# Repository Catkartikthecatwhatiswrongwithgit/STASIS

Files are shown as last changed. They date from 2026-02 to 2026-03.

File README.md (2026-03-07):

<div align="center">

```
███████╗ ████████╗  █████╗  ███████╗ ██╗ ███████╗
██╔════╝ ╚══██╔══╝ ██╔══██╗ ██╔════╝ ██║ ██╔════╝
███████╗    ██║    ███████║ ███████╗ ██║ ███████╗
╚════██║    ██║    ██╔══██║ ╚════██║ ██║ ╚════██║
███████║    ██║    ██║  ██║ ███████║ ██║ ███████║
╚══════╝    ╚═╝    ╚═╝  ╚═╝ ╚══════╝ ╚═╝ ╚══════╝
```

**Autonomous Hazard Monitoring Rover**
*Team EDGECASE*




[]()

</div>

---

## What is STASIS?

STASIS is a compact autonomous rover built for reliable real-world operation on a student budget. It patrols a defined area, detects hazards (fire, motion, seismic activity), sends SMS alerts, and returns to a charging dock using AprilTag visual guidance — all without human intervention.

It is designed to **work at a demo**, not just in a lab.

---

## System Architecture

```
┌───────────────────────────────────────────────────────────────┐
│                      ROVER  (Mobile)                          │
│                                                               │
│   ┌─────────────┐  UART   ┌────────────────────────────────┐  │
│   │  ESP32-CAM  │────────►│          ESP32-S3              │  │
│   │  (Vision)   │         │  State machine · Motors        │  │
│   └─────────────┘         │  Sensors · GPS · GSM · UART    │  │
│                           └──────────────┬─────────────────┘  │
│                                          │ ESP-NOW             │
└──────────────────────────────────────────┼─────────────────────┘
                                           │
┌──────────────────────────────────────────┼─────────────────────┐
│                   BASE STATION           │  (Static)           │
│                                          ▼                     │
│   ┌──────────────────┐  UART  ┌──────────────────┐            │
│   │   Raspberry Pi   │◄──────►│    ESP32-C3       │            │
│   │   Zero W         │        │  (Wireless bridge)│            │
│   │   Flask + SocketIO        └──────────────────┘            │
│   └────────┬─────────┘                                         │
│            │ HTTP + Socket.IO                                  │
└────────────┼──────────────────────────────────────────────────┘
             ▼
    ┌──────────────────────────┐
    │     Web Dashboard        │
    │  stasis_app/index.html   │   offline-safe, served from Pi
    └──────────────────────────┘
```

---

## Hardware

### Rover

| Component | Part | Role |
|---|---|---|
| Main MCU | ESP32-S3 | State machine, motor control, sensor fusion |
| Vision | ESP32-CAM (AI Thinker) | Fire / motion / human detection |
| Motor Driver | L9110S | 4WD differential drive |
| Obstacle | HC-SR04 | Non-blocking ultrasonic — stops at 25 cm |
| Temperature | DS18B20 | Environmental monitoring, fire threshold |
| Light | LDR | Ambient light / smoke indicator |
| GPS | NEO-6M | Geofence enforcement + home position |
| GSM | SIM800L | SMS alerts on hazard or geofence breach |
| Battery | 2S Li-ion 7.4 V | Monitored via ADC + 30k/10k divider |

### Base Station

| Component | Part | Role |
|---|---|---|
| Supervisor | Raspberry Pi Zero W | Flask API, AprilTag docking, PDF reports |
| Bridge | ESP32-C3 | ESP-NOW ↔ UART relay |
| Tag | tag36h11 ID 0, 10 cm | Visual beacon on docking station |

---

## State Machine

```
             ┌──────────────┐
   ┌─────────│  SAFE_IDLE   │◄──────────────────────┐
   │         └──────┬───────┘                       │
   │                │ PATROL or cmd                 │
   │                ▼                               │
   │         ┌──────────────┐  geofence/hazard      │
   │         │   PATROL     │────────────┐          │
   │         └──────┬───────┘            │          │
   │                │ hazard             │          │
   │                ▼                   │          │
   │         ┌──────────────┐           │          │
   │         │    ALERT     │─────timeout 30s──────►│
   │         └──────────────┘                      │
   │                                               │
   │  low bat / geofence                           │
   │         ┌──────────────┐                      │
   └────────►│ RETURN_BASE  │                      │
             └──────┬───────┘                      │
                    │ dockingEnabled                │
                    ▼                              │
             ┌──────────────┐  voltage rise        │
             │   DOCKING    │─────────────────────►│
             │ (AprilTag)   │                      │
             └──────────────┘                      │
                    │ docked                       │
                    ▼                              │
             ┌────────────────────┐                │
             │  DOCKED_CHARGING   │                │
             │  motors disabled   │────undocked───►│
             └────────────────────┘
```

| State | Description |
|---|---|
| `SAFE_IDLE` | Motors off, sensors active, waiting for command |
| `PATROL` | Autonomous patrol within GPS geofence |
| `ALERT` | Hazard confirmed — buzzer on, SMS sent, investigating |
| `RETURN_TO_BASE` | Low battery or geofence breach — heading home |
| `DOCKING` | Pi-guided AprilTag precision approach |
| `DOCKED_CHARGING` | Passive contact charging — motors fully disabled |

---

## AprilTag Docking

The Pi Zero runs a continuous visual docking control loop whenever the rover enters `STATE_DOCKING`.

```
ESP32-CAM MJPEG stream
        │
        ▼
  Pi Zero  (pupil-apriltags + OpenCV)
        │  detect tag36h11 ID 0
        │  measure: X error (steering) + Z depth (distance)
        ▼
  Proportional controller
    turn  = clamp(err_x × 0.6,  -100, +100)
    speed = clamp(dist_m × 40,    10,    40)
    if |err_x| < 15 px → turn = 0  (dead-band)
    if dist_m  < 0.25 m → DOCKED
        │
        ▼
  6-byte binary packet   [0xAA | turn | speed | docked | XOR | 0x55]
        │
        ▼
  UART → ESP32-C3 → ESP-NOW → ESP32-S3 → motors
```

**One-time setup on Pi:**
```bash
pip install pupil-apriltags opencv-python-headless
```

Print a `tag36h11` tag at **10 cm**, ID **0**. Mount it vertically on the docking station, facing the rover's approach path. Ensure there is consistent lighting.

---

## Quick Start

### 1. Flash firmware

```bash
# ESP32-S3 (rover main controller)
# Open: rover_main/rover_main.ino
# Board: ESP32S3 Dev Module  |  Upload speed: 921600

# ESP32-CAM (vision)
# Open: cam_firmware/cam_firmware.ino
# Board: AI Thinker ESP32-CAM  |  Connect IO0→GND during flash only

# ESP32-C3 (wireless bridge)
# Open: base_bridge/base_bridge.ino
# Board: ESP32C3 Dev Module
# ⚠  Set roverMac[] to your ESP32-S3's actual MAC address before flashing
```

### 2. Set up the Pi

```bash
# Install Python dependencies
pip install flask flask-cors flask-socketio pyserial fpdf2 eventlet
pip install pupil-apriltags opencv-python-headless

# Cache Leaflet maps for offline use (run once with internet access)
mkdir -p ~/stasis/static
wget -O ~/stasis/static/leaflet.css https://unpkg.com/leaflet@1.9.4/dist/leaflet.css
wget -O ~/stasis/static/leaflet.js  https://unpkg.com/leaflet@1.9.4/dist/leaflet.js

# Start the base station
python3 base_station/station_monitor.py
```

### 3. Auto-start on boot

```bash
sudo nano /etc/systemd/system/stasis.service
```

```ini
[Unit]
Description=STASIS Base Station
After=network.target

[Service]
User=pi
WorkingDirectory=/home/pi/stasis
ExecStart=/usr/bin/python3 /home/pi/stasis/base_station/station_monitor.py
Restart=always
RestartSec=10
Environment="SERIAL_PORT=/dev/serial0"
Environment="CAM_STREAM_URL=http://192.168.4.1:81/stream"

[Install]
WantedBy=multi-user.target
```

```bash
sudo systemctl daemon-reload && sudo systemctl enable --now stasis
```

### 4. Open the dashboard

Connect to the `Stasis-Base` WiFi AP (password: `stasis123`), then visit:

```
http://192.168.4.1:5000/stasis_app/index.html
```

---

## Commands

| Command | Action |
|---|---|
| `STOP` | Emergency stop → SAFE_IDLE |
| `FORWARD` | Drive forward |
| `BACKWARD` | Drive in reverse |
| `LEFT` / `RIGHT` | Turn |
| `PATROL` | Start autonomous patrol |
| `STOP_PATROL` | Stop patrol → SAFE_IDLE |
| `HOME` / `RETURN_BASE` | Return to dock |
| `DOCKING` | Enable AprilTag docking |
| `DISABLE_DOCKING` | Cancel docking |
| `SETHOME` | Save current GPS position as home |
| `RESET` | Reset all flags and states |

---

## Safety Features

| Feature | How it works |
|---|---|
| Obstacle stop | HC-SR04 non-blocking; halts at < 25 cm |
| GPS geofence | 50 m radius, Haversine calculation, 80 % hysteresis on re-entry |
| GPS staleness guard | `SAFE_HALT` if no fix > 5 s; 90 s grace period after cold boot |
| Dock detection | 0.4 V battery rise sustained across 20 frames (~2 s) |
| Emergency stop | `ledcWrite(pin, 0)` on all PWM channels — LEDC-safe |
| GSM brownout guard | Motors halted 100 ms before every SMS attempt |
| SMS rate limit | Maximum one SMS per 60 seconds |
| Low battery | Speed capped at 60 % below 20 %; `RETURN_TO_BASE` triggered |
| Hard voltage cutoff | Forced `SAFE_IDLE` at 6.2 V |
| Charge complete | Detected at 8.4 V or after 10-minute timeout |

---

## Repository Structure

```
STASIS/
├── rover_main/
│   └── rover_main.ino           ESP32-S3 main firmware
├── cam_firmware/
│   └── cam_firmware.ino         ESP32-CAM vision firmware
├── base_bridge/
│   └── base_bridge.ino          ESP32-C3 wireless bridge
├── base_station/
│   └── station_monitor.py       Pi: Flask API + AprilTag docking thread
├── stasis_app/
│   └── index.html               Web dashboard (offline-safe single file)
├── docking/
│   └── apriltag_docking.py      Standalone AprilTag docking utility
└── docs/
    ├── ESP32-S3_INSTRUCTIONS.md
    ├── ESP32-CAM_INSTRUCTIONS.md
    ├── ESP32-C3_INSTRUCTIONS.md
    ├── RPI0_INSTRUCTIONS.md
    ├── APRILTAG_DOCKING_GUIDE.md
    ├── WIRING_DIAGRAMS.md
    ├── PROTOCOL.md
    ├── QUICK_REFERENCE.md
    ├── SSH_PI0_SETUP.md
    └── 3D_PRINTED_PARTS.md
```

---

## Pin Reference (ESP32-S3)

| GPIO | Function | Notes |
|---|---|---|
| 1 | Battery ADC | 30 kΩ / 10 kΩ divider → reads 0–3.3 V for 0–13.2 V |
| 2 | Motor A DIR | L9110S |
| 4 | Motor A PWM | L9110S — LEDC channel |
| 5 | Motor B PWM | L9110S — LEDC channel |
| 6 | Motor C PWM | L9110S — LEDC channel |
| 7 | Motor C DIR | L9110S |
| 8 | GPS Serial2 RX | NEO-6M TX |
| 9 | Ultrasonic ECHO | HC-SR04 |
| 10 | Ultrasonic TRIG | HC-SR04 |
| 12 | SIM800 RX | **Serial1** — not Serial2 |
| 13 | SIM800 TX | **Serial1** — not Serial2 |
| 14 | Buzzer | Active buzzer |
| 15 | Motor D PWM | L9110S — LEDC channel |
| 16 | Motor D DIR | L9110S |
| 18 | Motor B DIR | L9110S |
| 19 | GPS Serial2 TX | NEO-6M RX |
| 21 | DS18B20 | OneWire + 4.7 kΩ pull-up to 3.3 V |
| 43 | UART1 TX | Pi Zero RX (via ESP32-C3) |
| 44 | UART1 RX | Pi Zero TX (via ESP32-C3) |
| 45 | Status LED | – |

---

## Changelog — v2 (March 2026)

| # | Issue | Fix |
|---|---|-----|
| C1 | `estop()` used `digitalWrite` on LEDC pins — motors did not stop | Changed to `ledcWrite(pin, 0)` |
| C2 | `BACKWARD` command called `drive(0,0)` immediately, cancelling the speed | Fixed to set `currentSpeed = -50` |
| C3 | `chargeBeepDone` declared as local `static` inside `executeState()`, shadowing global | Removed local declaration; uses global |
| C4 | GPS and SIM800 both on Serial2 — corrupted each other | SIM800 moved to Serial1 (pins 12, 13) |
| C5 | Global variables used but never declared — code would not compile | Added full globals block after enum declarations |
| C6 | AprilTag docking existed in spec but was not implemented anywhere | Full Pi-side docking thread added to `station_monitor.py` |
| C7 | `uartTask` only called `parseDockCommand` on the header byte; bytes 2–6 routed to text parser | Added `binaryMode` flag to capture entire packet |
| I1 | `captureAndSend()` wrote raw binary struct then text on same Serial — corrupted S3 parser | Binary write removed; text-only output |
| I2 | GPS staleness check halted rover immediately on cold boot before any fix acquired | Added 90-second startup grace period |
| I3 | FreeRTOS task stacks set to 2048 bytes — overflowed on String / float operations | Increased to 3072–4096 bytes per task |
| W1 | `L is not defined` (×6) — Leaflet CDN unavailable on isolated AP network | Dynamic loader: CDN → `/static/leaflet.js` → offline message |
| W2 | Chat used raw `WebSocket` — Flask-SocketIO uses Socket.IO framing, not raw WS | Replaced with Socket.IO `io()` client |
| W3 | Font Awesome CDN missing on offline AP — all icons blank | Replaced with inline SVG, zero CDN dependency |

---

*Team EDGECASE · March 2026*

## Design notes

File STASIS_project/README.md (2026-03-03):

# STASIS Autonomous Rover — Team EDGECASE

STASIS is a compact autonomous hazard-monitoring rover designed for reliable real-world operation under tight budget constraints.

This project focuses on robustness, deterministic behavior, and competition-ready autonomy rather than experimental features.

---

## Core Capabilities

* Autonomous patrol
* Obstacle avoidance (HC-SR04)
* Environmental sensing (DS18B20, LDR)
* GPS tracking with virtual geofence (NEO-6M)
* GSM hazard alerts (SIM800)
* AprilTag-assisted precision docking
* Passive contact-pad charging
* Multi-MCU distributed architecture
* Raspberry Pi mission logging
* Live telemetry dashboard

---

## System Architecture

### Rover (ESP32-S3)

Primary responsibilities:

* state machine control
* motor control (L9110S)
* sensor fusion
* dock detection
* return-to-base logic
* GSM alert triggering

### Vision Node (ESP32-CAM)

* AprilTag detection
* snapshot capture
* hazard flag signaling

### Base Bridge (ESP32-C3)

* wireless/serial relay
* packet forwarding
* base communications

### Supervisor (Raspberry Pi Zero W)

* mission logging
* evidence storage
* dashboard hosting
* system monitoring

---

## Charging System

STASIS uses passive contact-pad charging:

Dock side:

* regulated 5V supply
* exposed screw-head contacts
* mechanical alignment funnel

Rover side:

* spring metal wipers
* onboard Li-ion charger

Dock detection is performed via battery voltage rise with hysteresis filtering.

---

## Rover State Machine

Primary states:

* PATROL
* ALERT
* RETURN_TO_BASE
* DOCKED_CHARGING
* SAFE_IDLE

All transitions are non-blocking and millis()-driven.

---

## Repository Structure

* rover_s3_firmware/ — main rover firmware
* cam_firmware/ — ESP32-CAM code
* base_bridge/ — ESP32-C3 bridge
* base_station/ — Raspberry Pi services
* stasis_app/ — web dashboard
* docking/ — AprilTag utilities
* docs/ — system documentation

---

## Design Philosophy

STASIS prioritizes:

* deterministic behavior
* electrical tolerance
* mechanical forgiveness
* low-cost components
* competition reliability

This is a field-robust student platform, not a lab-only prototype.

---

## Status

Active development.
Focused on competition reliability and system hardening.

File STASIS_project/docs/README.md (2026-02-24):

# STASIS - Autonomous Environmental Monitoring Rover

A production-ready autonomous rover system for environmental monitoring, hazard detection, and autonomous docking. Built with ESP32-S3, Raspberry Pi Zero, and modular sensor integration.

---

## System Architecture

```
┌─────────────────────────────────────────────────────────────────────────────┐
│                           STASIS ROVER SYSTEM                                │
├─────────────────────────────────────────────────────────────────────────────┤
│                                                                             │
│   ┌──────────────┐    ┌──────────────┐    ┌──────────────┐                 │
│   │   ROVER     │    │    BASE      │    │   REMOTE    │                 │
│   │   (Mobile)  │◄──►│  (Station)   │◄──►│  (Dashboard)│                 │
│   └──────┬───────┘    └──────┬───────┘    └──────────────┘                 │
│          │                   │                                             │
│          │    ┌──────────────┴───────┐                                   │
│          │    │   COMMUNICATION      │                                   │
│          │    │   • ESP-NOW          │                                   │
│          │    │   • UART (Pi↔ESP32)  │                                   │
│          │    │   • WiFi (Dashboard) │                                   │
│          │    └───────────────────────┘                                   │
│          │                                                                   │
│   ┌──────┴────────────────────────────────────────────────────────┐       │
│   │                     ROVER HARDWARE                             │       │
│   ├───────────────────────────────────────────────────────────────┤       │
│   │  ESP32-S3 (Main Controller)                                   │       │
│   │    ├── Navigation & State Machine                            │       │
│   │    ├── Motor Control (L9110S)                                │       │
│   │    ├── Sensor Fusion                                         │       │
│   │    └── Communication Bridge                                  │       │
│   │                                                               │       │
│   │  ESP32-CAM (Vision)                                          │       │
│   │    ├── Fire Detection                                         │       │
│   │    ├── Human Detection                                        │       │
│   │    └── Tree Detection                                         │       │
│   │                                                               │       │
│   │  Sensors                                                     │       │
│   │    ├── DS18B20 (Temperature)                                 │       │
│   │    ├── HC-SR04 (Ultrasonic)                                  │       │
│   │    ├── MPU6050 (Tilt/Seismic)                               │       │
│   │    └── Neo-6M (GPS)                                          │       │
│   │                                                               │       │
│   │  Communication                                                │       │
│   │    ├── SIM800 (SMS Alerts)                                   │       │
│   │    └── ESP-NOW (Base Link)                                   │       │
│   └───────────────────────────────────────────────────────────────┘       │
│                                                                             │
└─────────────────────────────────────────────────────────────────────────────┘
```

---

## Hardware List

### Rover
| Component | Model | Purpose |
|---|---|---|
| Main MCU | ESP32-S3 | Navigation, state machine, motor control |
| Camera | ESP32-CAM | Fire/human/tree detection |
| Motor Driver | L9110S | 4WD differential drive |
| Temperature | DS18B20 | Environmental monitoring |
| Ultrasonic | HC-SR04 | Obstacle avoidance |
| IMU | MPU6050 | Tilt/seismic detection |
| GPS | Neo-6M | Location tracking |
| Modem | SIM800 | SMS alerts |
| Battery | LiPo 3S | Power |

### Base Station
| Component | Model | Purpose |
|---|---|---|
| Processing | Raspberry Pi Zero | AprilTag detection |
| Bridge | ESP32-C3 | UART↔ESP-NOW |
| Vision | USB Camera | AprilTag detection |
| Display | I2C LCD | Status display |
| Tag | AprilTag 36h11 | Docking beacon |

---

## State Machine

```
                    ┌──────────────────────────────────────┐
                    │                                      │
                    ▼                                      │
    ┌───────────────────────────┐                          │
    │         PATROL            │◄─────────────────────────┤
    │  (Normal operation)       │                          │
    └─────────────┬─────────────┘                          │
                  │                                         │
    ┌─────────────┴─────────────┐     ┌───────────────────┐ │
    │                           │     │                   │ │
    ▼                           ▼     ▼                   ▼ │
┌────────────┐  ┌──────────────────┐  ┌────────────────┐    │
│  RESEARCH  │  │ RETURN_TO_BASE  │  │     DOCKING    │    │
│(Data collect)│ │ (Low battery)   │  │ (AprilTag)    │    │
└──────┬──────┘  └────────┬─────────┘  └───────┬────────┘    │
       │                 │                      │             │
       │    ┌────────────┴──────────┐           │             │
       │    │                      │           │             │
       ▼    ▼                      ▼           ▼             │
┌──────────────────────────────────────────────────────────┐ │
│                        ALERT                              │ │
│  (Fire/Earthquake/Intruder - Investigate & Alert)       │ │
└──────────────────────────────────────────────────────────┘ │
                              │                              │
                              │     ┌───────────────────────┘
                              │     │
                              ▼     ▼
                    ┌──────────────────┐
                    │     DOCKED       │
                    │ (Charging/Idle)  │
                    └──────────────────┘
```

### State Transitions

| From State | To State | Trigger Condition |
|---|---|---|
| PATROL | RESEARCH | Timer or command |
| PATROL | ALERT | fireDetected OR humanDetected OR tiltDetected |
| PATROL | RETURN_TO_BASE | batteryPercent < 30% |
| PATROL | DOCKING | dockingEnabled = true |
| RESEARCH | PATROL | Timeout (5 min) |
| RESEARCH | ALERT | Hazard detected |
| ALERT | PATROL | Timeout or resolved |
| RETURN_TO_BASE | DOCKING | dockingEnabled = true |
| DOCKING | DOCKED | Successfully docked |
| DOCKED | PATROL | dockingEnabled = false |

---

## Folder Structure

```
STASIS-Rover/
├── .gitignore
├── README.md
├── LICENSE
│
├── rover_s3_firmware/          # ESP32-S3 main controller
│   ├── platformio.ini
│   ├── src/
│   │   └── rover_main.cpp
│   └── lib/
│       └── (dependencies)
│
├── esp32_cam_firmware/         # ESP32-CAM vision
│   ├── cam_firmware.ino
│   └── libraries/
│
├── base_station_c3/            # ESP32-C3 bridge
│   ├── platformio.ini
│   └── src/
│       └── bridge.cpp
│
├── pi_zero_station/            # Raspberry Pi Zero
│   ├── requirements.txt
│   ├── apriltag_docking.py    # AprilTag detection + control
│   ├── station_monitor.py     # Main station logic
│   └── config/
│       └── camera_calibration.json
│
├── cad/                        # 3D printed parts
│   └── (STL files)
│
└── docs/
    ├── PROTOCOL.md            # Communication protocols
    ├── HARDWARE.md           # Wiring diagrams
    ├── CALIBRATION.md        # Sensor calibration
    └── TROUBLESHOOTING.md    # Common issues
```

---

## Quick Start

### 1. Hardware Assembly

1. **Motor Driver**: Connect L9110S to ESP32-S3 GPIO pins (see `WIRING_DIAGRAMS.md`)
2. **Sensors**: Wire DS18B20, HC-SR04, MPU6050 per pin definitions
3. **GPS**: Connect Neo-6M to UART2
4. **SIM800**: Connect to UART0 with level shifting

### 2. Base Station Setup

```bash
# Install dependencies
cd pi_zero_station
pip install -r requirements.txt

# Run AprilTag docking system
python apriltag_docking.py --device /dev/ttyUSB0
```

### 3. Rover Flash

```bash
# Using PlatformIO
cd rover_s3_firmware
pio run --target upload
```

### 4. Commissioning

1. Verify all sensors respond
2. Test motor direction
3. Calibrate camera focal length
4. Test AprilTag detection at various distances
5. Verify ESP-NOW pairing

---

## Command Protocol

### Pi Zero → ESP32-S3 (Docking)

| Byte | Field | Range |
|---|---|---|
| 0 | HEADER | 0xAA |
| 1 | turn | -100 to +100 |
| 2 | speed | 0-100 |
| 3 | docked | 0 or 1 |
| 4 | checksum | XOR(1,2,3) |
| 5 | TAIL | 0x55 |

### ESP32-S3 → Base (Telemetry)

See `docs/PROTOCOL.md` for full specification.

---

## Current Limitations

- **GPS**: Neo-6M requires clear sky view; indoor operation limited
- **AprilTag**: Requires adequate lighting; performance degrades in low-light
- **WiFi**: Range limited to ~100m outdoors; use ESP-NOW for extended range
- **Battery**: Actual runtime depends on terrain and load; 30% threshold is conservative

---

## Future Work

- [ ] Implement SLAM for autonomous navigation
- [ ] Add machine learning for hazard classification
- [ ] Multi-rover coordination via ESP-NOW mesh
- [ ] Solar charging integration
- [ ] Web interface for real-time monitoring

---

## License

MIT License - See LICENSE file

---

## Authors

- EdgeCase Team

## Acknowledgments

- AprilTag library by University of Michigan
- ESP32 Arduino framework

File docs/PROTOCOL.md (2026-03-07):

# STASIS Communication Protocols

---

## Architecture Summary

```
ESP32-CAM ──Serial──► ESP32-S3 ──ESP-NOW──► ESP32-C3 ──UART──► Raspberry Pi
                        (rover)              (bridge)             (Flask API)
                           ▲                                          │
                           └──────────── binary DockCommand ◄─────────┘
                                         (during docking only)
```

---

## 1. Camera → Rover (Serial, UART0)

The ESP32-CAM sends plain-text messages to the ESP32-S3 over its default Serial port at 115200 baud.

**Output from ESP32-CAM:**

| Message | Meaning |
|---|---|
| `CAM:READY` | Camera initialised successfully |
| `CAM:ERROR` | Camera failed to initialise |
| `HAZARD:FIRE` | Fire pixels detected above threshold |
| `HAZARD:MOTION` | Motion pixels detected above threshold |
| `HAZARD:HUMAN` | Skin-tone pattern detected above threshold |
| `CLEAR` | No hazards in current frame |

> **Note (v2):** Binary `DetectionResult` struct writes were removed. All output is text-only. This eliminates corruption of the S3's line parser.

**Commands from ESP32-S3 to ESP32-CAM (single byte):**

| Byte | Command | Effect |
|---|---|---|
| `0x01` | CAPTURE | Capture one frame and return detection result |
| `0x02` | STREAM_ON | Start continuous MJPEG stream |
| `0x03` | STREAM_OFF | Stop streaming |
| `0x04` | DETECT | Run detection only, no stream |
| `0x05` | APRIL_STREAM | Switch to JPEG mode and start streaming (for AprilTag) |

---

## 2. Rover → Base (ESP-NOW, wireless)

The ESP32-S3 broadcasts telemetry to the ESP32-C3 bridge via ESP-NOW at approximately 1 Hz.

**Telemetry packet (JSON, forwarded to Pi over UART):**

```json
{
  "id":       123,
  "temp":     25.5,
  "bat":      82.0,
  "lat":      12.345678,
  "lng":      77.123456,
  "hazard":   false,
  "status":   "PATROL",
  "distance": 142.3,
  "speed":    40,
  "heading":  180.0
}
```

| Field | Type | Description |
|---|---|---|
| `id` | int | Incrementing packet counter |
| `temp` | float | DS18B20 temperature in °C |
| `bat` | float | Battery percentage (0–100) |
| `lat` / `lng` | float | GPS coordinates (decimal degrees) |
| `hazard` | bool | True if any hazard is active |
| `status` | string | Current state name |
| `distance` | float | Ultrasonic reading in cm |
| `speed` | int | Current motor speed (0–100) |
| `heading` | float | Compass heading in degrees (if available) |

**Status values:**

| Value | State |
|---|---|
| `SAFE_IDLE` | Idle |
| `PATROL` | Autonomous patrol |
| `ALERT` | Hazard detected |
| `RETURN_TO_BASE` | Returning home |
| `DOCKING` | AprilTag approach active |
| `DOCKED_CHARGING` | On charge |

---

## 3. Pi → Rover (UART → ESP32-C3 → ESP-NOW)

### 3a. Text commands (all states except DOCKING)

Plain text strings terminated with `\n`. The bridge forwards them to the rover via ESP-NOW.

| Command | Effect |
|---|---|
| `STOP` | Emergency stop |
| `FORWARD` | Drive forward at speed 50 |
| `BACKWARD` | Drive in reverse at speed 50 |
| `LEFT` | Turn left |
| `RIGHT` | Turn right |
| `PATROL` | Start autonomous patrol |
| `STOP_PATROL` | Stop patrol |
| `HOME` / `RETURN_BASE` / `RETURN_HOME` | Return to dock |
| `DOCKING` / `ENABLE_DOCKING` | Activate docking mode |
| `DISABLE_DOCKING` | Cancel docking |
| `SETHOME` | Set current GPS as home |
| `ALERT` | Force ALERT state |
| `RESET` | Reset all state flags |

### 3b. Binary DockCommand packets (DOCKING state only)

During `STATE_DOCKING`, the Pi sends 6-byte binary packets at ~20 Hz. These bypass the text parser.

```
Byte  Field     Type    Range
  0   Header    uint8   0xAA  (fixed)
  1   turn      int8    -100 to +100  (negative = left, positive = right)
  2   speed     uint8   0 to 100
  3   docked    uint8   0 or 1
  4   checksum  uint8   XOR(byte1, byte2, byte3)
  5   Tail      uint8   0x55  (fixed)
```

The rover uses a `binaryMode` flag in `uartTask` to capture all 6 bytes before parsing. The `parseDockCommand()` function validates header, tail, and XOR checksum before accepting a packet.

---

## 4. Pi REST API

Base URL: `http://192.168.4.1:5000`

Most endpoints require the API key header: `X-API-Key: stasis-2024`

| Endpoint | Method | Auth | Description |
|---|---|---|---|
| `/api/health` | GET | No | Liveness check |
| `/api/status` | GET | Yes | Latest telemetry JSON |
| `/api/history` | GET | Yes | Telemetry history (`?limit=N`) |
| `/api/alerts` | GET | Yes | Alert history |
| `/api/stats` | GET | Yes | Daily statistics |
| `/api/command` | POST | Yes | Send command: `{"cmd": "PATROL"}` |
| `/api/reports` | GET | Yes | List PDF reports |
| `/api/reports/<file>` | GET | Yes | Download a report |
| `/api/export/csv` | GET | Yes | Export telemetry as CSV |
| `/api/export/json` | GET | Yes | Export telemetry as JSON |
| `/api/config` | GET/POST | Yes | Read / write config |

### Socket.IO events (real-time)

Connect with `io()` (no URL argument — auto-connects to origin).

| Event | Direction | Payload |
|---|---|---|
| `telemetry` | Server → Client | Latest telemetry object |
| `alert` | Server → Client | Alert object |
| `chat` | Bidirectional | `{user, message, channel, timestamp}` |
| `user_joined` | Server → Client | `{user}` |
| `user_left` | Server → Client | `{user}` |
| `apriltag` | Server → Client | `{found, tag_id, err_x, dist_m}` |
| `connected` | Server → Client | `{message}` on first connect |

---

## 5. Timing

| Data stream | Rate | Method |
|---|---|---|
| Rover telemetry | ~1 Hz | ESP-NOW broadcast |
| Dock command packets | ~20 Hz | UART binary during DOCKING only |
| Camera hazard messages | Event-driven | UART text |
| AprilTag Socket.IO events | ~20 Hz | Socket.IO during DOCKING only |
| Battery updates | 10 Hz | Internal (sensorTask) |
| GPS NMEA | 1 Hz | Serial2 hardware UART |

---

*Last updated: March 2026 — v2*

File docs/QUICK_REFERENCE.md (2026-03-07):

# STASIS — Quick Reference Card

---

## Commands

| Command | Action |
|---|---|
| `STOP` | Emergency stop → SAFE_IDLE |
| `FORWARD` | Drive forward |
| `BACKWARD` | Drive in reverse |
| `LEFT` / `RIGHT` | Turn |
| `PATROL` | Start autonomous patrol |
| `STOP_PATROL` | Stop patrol → SAFE_IDLE |
| `HOME` / `RETURN_BASE` | Return to dock |
| `DOCKING` | Enable AprilTag docking |
| `DISABLE_DOCKING` | Cancel docking |
| `SETHOME` | Set current GPS as home (requires fix) |
| `RESET` | Reset all flags and state |

---

## States

| State | LED | Buzzer |
|---|-----|---|
| `SAFE_IDLE` | 1 Hz slow blink | Off |
| `PATROL` | Solid | Off |
| `ALERT` | 5 Hz fast blink | 2 Hz |
| `RETURN_TO_BASE` | 2 Hz medium blink | Off |
| `DOCKING` | Off | Off |
| `DOCKED_CHARGING` | Solid | Off |

---

## Pin Map (ESP32-S3)

```
Motors:      2, 4, 5, 6, 7, 15, 16, 18   (L9110S 4WD)
Ultrasonic:  9 (ECHO), 10 (TRIG)          (HC-SR04)
GPS:         8 (RX), 19 (TX)              (NEO-6M, Serial2)
SIM800:      12 (RX), 13 (TX)             (Serial1 — NOT Serial2)
DS18B20:     21                            (OneWire + 4.7k pull-up)
Battery ADC: 1                             (30k/10k divider)
Buzzer:      14
Status LED:  45
UART to Pi:  43 (TX), 44 (RX)
```

> Serial2 = GPS only. Serial1 = SIM800 only. They must not be swapped.

---

## Safety Thresholds

| Parameter | Value |
|---|---|
| Obstacle stop | < 25 cm |
| Geofence radius | 50 m |
| GPS staleness halt | > 5 s (after 90 s cold-start grace) |
| Dock confirm voltage | +0.4 V above baseline |
| Dock debounce | 20 frames (~2 s) |
| Low battery speed limit | 20 % → 60 % speed cap |
| Hard voltage cutoff | 6.2 V |
| Charge complete | 8.4 V or 10 min |
| SMS cooldown | 60 s |

---

## AprilTag Docking Checklist

- [ ] Tag family: tag36h11, ID 0, size 10 cm
- [ ] Tag mounted perpendicular to approach path
- [ ] Consistent lighting on tag face
- [ ] `pip install pupil-apriltags opencv-python-headless` on Pi
- [ ] `CAM_STREAM_URL` set correctly (default: `http://192.168.4.1:81/stream`)
- [ ] Camera stream reachable: `curl -I http://192.168.4.1:81/stream`
- [ ] Rover reports `STATE_DOCKING` in telemetry to activate thread

---

## Dashboard Access

Connect to WiFi AP: **Stasis-Base** (password: `stasis123`)

```
Dashboard:  http://192.168.4.1:5000/stasis_app/index.html
API status: http://192.168.4.1:5000/api/health
API key:    stasis-2024
```

Keyboard shortcuts in dashboard:

| Key | Action |
|-----|---|
| `1`–`6` | Switch panel |
| `Space` | STOP |
| `P` | PATROL |
| `H` | HOME |
| `F` | Fencing panel |

---

## Common Problems

| Symptom | Fix |
|---|-----|
| Rover won't stop in emergency | Flash v2 firmware — `estop()` was broken |
| BACKWARD drives forward | Flash v2 firmware — speed sign was wrong |
| GPS halts rover on boot | Flash v2 firmware — 90 s grace period added |
| SMS sends but GPS garbled | SIM800 must be on Serial1, GPS on Serial2 |
| Docking doesn't steer | Check `binaryMode` flag in `uartTask` |
| `L is not defined` on dashboard | Cache Leaflet locally on Pi |
| Chat not working | Socket.IO required — not raw WebSocket |
| All dashboard icons blank | Inline SVG fix in v2 dashboard |
| Map shows in wrong place | Check GPS home fix, verify lat/lng sign |

---

## Useful Pi Commands

```bash
# Check service status
sudo systemctl status stasis

# View live logs
journalctl -u stasis -f

# Restart service
sudo systemctl restart stasis

# Test serial comms
minicom -D /dev/serial0 -b 115200

# Send a manual command
curl -X POST http://localhost:5000/api/command \
  -H "Content-Type: application/json" \
  -H "X-API-Key: stasis-2024" \
  -d '{"cmd":"STOP"}'
```

---

*Last updated: March 2026 — v2*

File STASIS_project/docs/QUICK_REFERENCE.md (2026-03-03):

================================================================================
STASIS ROVER - QUICK REFERENCE
================================================================================

## Commands
------------------------------------------------------------------------------
STOP              → Emergency stop
PATROL            → Start autonomous patrol
STOP_PATROL       → Stop patrol
HOME/RETURN_BASE  → Return to dock
DOCKING           → Enable AprilTag docking
SETHOME           → Set current GPS as home position
RESET             → Reset all states

## States
------------------------------------------------------------------------------
SAFE_IDLE         - Waiting, minimal power
PATROL            - Autonomous patrol
ALERT             - Hazard detected
RETURN_TO_BASE    - Returning home
DOCKING           - AprilTag approach
DOCKED_CHARGING   - Charging

## Safety Features
------------------------------------------------------------------------------
✓ Dock detection: 0.4V rise, 2s confirm, 20-frame debounce
✓ GPS geofence: 50m radius, ignores 0.0,0.0
✓ GPS staleness: SAFE_HALT after 5s no fix
✓ SIM800: Motors stop before SMS, 60s cooldown
✓ Ultrasonic: Non-blocking, 30ms timeout
✓ Motor ramping: Smooth acceleration

## Pin Map
------------------------------------------------------------------------------
Motors:    2,4,5,6,7,15,16,18
Ultrasonic: 9,10
GPS:       8,19
SIM800:    12,13
Buzzer:    14
LED:       45
Battery:   1

## Troubleshooting
------------------------------------------------------------------------------
No GPS fix:     Wait 30-60s outdoors, check antenna
Dock false positive: Increase DOCK_VOLTAGE_RISE
SMS not sending: Check SIM balance, power (2A)
Motors jerky:   Check power supply, reduce speed
Rover frozen:   Check ultrasonic timeout, reduce debug output

================================================================================

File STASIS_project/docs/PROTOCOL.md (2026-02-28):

# STASIS Communication Protocols

This document describes all communication protocols used in the STASIS rover system.

---

## Table of Contents

1. [ESP-NOW Protocol](#esp-now-protocol)
2. [UART Protocol](#uart-protocol)
3. [Command Format](#command-format)
4. [Telemetry Format](#telemetry-format)
5. [Camera Messages](#camera-messages)

---

## ESP-NOW Protocol

### Overview

ESP-NOW is used for wireless communication between the rover (ESP32-S3) and base station bridge (ESP32-C3).

- **Range**: Up to 500m outdoors with external antenna
- **Latency**: ~5-10ms
- **Frequency**: 2.4 GHz WiFi band

### MAC Addresses

Each device must have a unique MAC address. Default addresses:

| Device | MAC Address |
|---|---|
| ESP32-S3 (Rover) | `30:AE:A4:XX:XX:XX` |
| ESP32-C3 (Base) | `DC:54:75:XX:XX:XX` |

### Message Types

| Type ID | Direction | Description |
|---|---|---|
| 0x01 | Rover → Base | Telemetry packet (JSON) |
| 0x02 | Base → Rover | Command packet |
| 0x03 | Bidirectional | Heartbeat/keepalive |

---

## UART Protocol

### Overview

UART is used for communication between ESP32-C3 (bridge) and Raspberry Pi Zero.

- **Baud Rate**: 115200
- **Data Bits**: 8
- **Parity**: None
- **Stop Bits**: 1

### Data Flow

```
ESP32-S3 (Rover) --ESP-NOW--> ESP32-C3 (Bridge) --UART--> Raspberry Pi Zero
                           (JSON parsing)         (station_monitor.py)
```

---

## Command Format

### Rover Commands (Pi → Rover)

Commands sent from Raspberry Pi to rover via ESP32-C3 bridge.

| Command | Description |
|---|---|
| `STOP` | Emergency stop |
| `FORWARD` | Move forward |
| `BACKWARD` | Move backward |
| `LEFT` | Turn left |
| `RIGHT` | Turn right |
| `START_PATROL` | Start autonomous patrol |
| `PATROL` | Start autonomous patrol (alias) |
| `STOP_PATROL` | Stop patrol |
| `RETURN_BASE` | Return to base station |
| `RETURN_HOME` | Return to base station (alias) |
| `HOME` | Return to base station (alias) |
| `START_RESEARCH` | Start research/investigation mode |
| `RESEARCH` | Start research mode (alias) |
| `ENABLE_DOCKING` | Enable AprilTag docking mode |
| `DOCKING` | Docking mode (alias) |
| `DISABLE_DOCKING` | Disable docking mode |
| `ALERT` | Trigger alert |
| `RESET` | Reset rover |

---

## Telemetry Format

### Rover Telemetry (JSON)

Telemetry sent from rover to base station. Format:

```json
{
  "id": 123,
  "temp": 25.5,
  "bat": 85.0,
  "lat": 12.3456,
  "lng": 78.9012,
  "hazard": false,
  "status": "PATROL",
  "distance": 150.5,
  "accelX": 0.1,
  "accelY": 0.05
}
```

### Status Values

| Value | State | Description |
|---|---|---|
| PATROL | PATROL | Normal patrol operation |
| RESEARCH | RESEARCH | Research mode |
| ALERT | ALERT | Hazard detected |
| RETURN_BASE | RETURN_BASE | Low battery return |
| DOCKING | DOCKING | AprilTag docking |
| DOCKED | DOCKED | Successfully docked |
| IDLE | IDLE | Idle/standby |
| EMERGENCY | EMERGENCY | Critical error |

---

## Camera Messages

### Non-JSON Messages from ESP32-CAM

The ESP32-CAM sends text messages that are parsed by station_monitor.py:

| Message | Description |
|---|---|
| `HAZARD:FIRE` | Fire detected by camera |
| `HAZARD:MOTION` | Motion detected |
| `HAZARD:HUMAN` | Human detected |
| `CAM:READY` | Camera initialized |
| `CAM:ERROR` | Camera error |
| `ERROR:...` | Generic error |

### Message Handling

The Pi parses these messages and:
1. Adds them to alert history
2. Broadcasts via WebSocket to connected clients
3. Logs warnings for hazard messages

---

## Communication Timing

### Update Rates

| Data | Rate | Method |
|---|---|---|
| Telemetry | 1 Hz | ESP-NOW |
| Commands | As needed | ESP-NOW |
| Camera Messages | Event-based | UART |

### Timeouts

| Condition | Timeout | Action |
|---|---|---|
| No telemetry | 10 seconds | Mark rover offline |
| No command (docking) | 500 ms | Emergency stop |

---

## API Endpoints

### Base Station (station_monitor.py)

| Endpoint | Method | Description |
|---|---|---|
| `/api/status` | GET | Latest telemetry |
| `/api/history` | GET | Telemetry history (limit param) |
| `/api/stats` | GET | Daily statistics |
| `/api/alerts` | GET | Alert history |
| `/api/command` | POST | Send command to rover |
| `/api/reports` | GET | List generated reports |
| `/api/reports/<filename>` | GET | Download report |
| `/api/health` | GET | System health (no auth) |
| `/api/config` | GET/POST | Configuration |
| `/api/config/sms` | GET/POST | SMS recipients |
| `/api/export/csv` | GET | Export telemetry as CSV |
| `/api/export/json` | GET | Export telemetry as JSON |
| `/ws` | WebSocket | Real-time chat/telemetry |

### Authentication

Most endpoints require API key in header:
- Header: `X-API-Key: stasis-2024` (default)
- Or query param: `?api_key=stasis-2024`
- `/api/health` is public (no auth required)

---

## Notes

1. All multi-byte integers are sent little-endian
2. GPS coordinates are in decimal degrees (WGS84)
3. Temperature is in Celsius
4. Distance is in centimeters
5. Accelerometer values are in m/s²

---

*Document Version: 2.0*
*Last Updated: February 2026*

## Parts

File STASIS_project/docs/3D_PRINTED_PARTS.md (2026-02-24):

# 3D Printed Parts - Stasis Rover

This document describes the 3D printed parts used in the Stasis rover system.

---

## Overview

The rover chassis and enclosure are designed to be 3D printed. All parts are located in the `Roverproject.zip` archive in the root directory.

---

## Parts List

### 1. Base Chassis

| File | Description |
|---|---|
| `base-Body.stl` | Original base chassis design |
| `base resized-Body.stl` | Resized version of the base chassis |

**Purpose:** The main chassis that holds all electronics, motors, and sensors.

**Print Settings:**
- Material: PETG or PLA+
- Layer Height: 0.2mm
- Infill: 30-40%
- Supports: Required for overhangs
- Wall Thickness: 3 perimeters minimum

**Dimensions:**
- Original: Standard rover size
- Resized: Adjusted for specific component fit

---

### 2. Lid/Cover

| File | Description |
|---|---|
| `lid-Body.stl` | Original lid design |
| `lid resize-Body.stl` | Resized version of the lid |

**Purpose:** Top cover that protects internal components and provides mounting for sensors.

**Print Settings:**
- Material: PETG or PLA+
- Layer Height: 0.2mm
- Infill: 20-30%
- Supports: Required
- Wall Thickness: 3 perimeters

**Features:**
- Camera mounting hole
- Sensor access points
- Ventilation slots

---

### 3. Roof

| File | Description |
|---|---|
| `roof-Body.stl` | Original roof design |
| `roof resized-Body.stl` | Resized version of the roof |

**Purpose:** Weather protection layer above the lid.

**Print Settings:**
- Material: PETG (recommended for outdoor use)
- Layer Height: 0.2mm
- Infill: 20%
- Supports: Minimal
- Wall Thickness: 2-3 perimeters

---

### 4. Legs (Suspension/Wheels)

#### Long Legs

| File | Description |
|---|---|
| `long leg-Body.stl` | Original long leg design |
| `Long leg resized-Body.stl` | Resized long leg |

**Purpose:** Longer suspension arms for rough terrain capability.

**Print Settings:**
- Material: PETG or TPU (for flexibility)
- Layer Height: 0.15-0.2mm
- Infill: 40-50%
- Supports: Yes
- Wall Thickness: 4 perimeters

#### Short Legs

| File | Description |
|---|---|
| `short leg-Body.stl` | Original short leg design |
| `short leg resized-Body.stl` | Resized short leg |

**Purpose:** Shorter suspension arms for standard terrain.

**Print Settings:**
- Material: PETG or TPU
- Layer Height: 0.15-0.2mm
- Infill: 40-50%
- Supports: Yes
- Wall Thickness: 4 perimeters

#### Leg Set

| File | Description |
|---|---|
| `legs resized.stl` | Complete set of resized legs |

**Purpose:** All four legs in a single print layout.

---

### 5. File Enclosure

| File | Description |
|---|---|
| `file enclosure-Body.stl` | Electronics enclosure |

**Purpose:** Houses the ESP32-S3, motor drivers, and other electronics.

**Print Settings:**
- Material: PETG
- Layer Height: 0.2mm
- Infill: 30%
- Supports: Required for internal features
- Wall Thickness: 3 perimeters

**Features:**
- Mounting points for PCBs
- Cable routing channels
- Ventilation for heat dissipation

---

## Print Recommendations

### Material Selection

| Material | Pros | Cons | Recommended For |
|---|---|---|---|
| **PETG** | Weather resistant, strong, flexible | Stringing, harder to print | Outdoor parts, chassis |
| **PLA+** | Easy to print, strong | Not heat resistant | Indoor parts, prototypes |
| **TPU** | Flexible, impact resistant | Difficult to print | Legs, bumpers |
| **ABS** | Heat resistant, strong | Warping, fumes | High-temperature applications |

### Print Orientation

For best strength and surface finish:

1. **Base Chassis:** Print upside down (flat side on bed)
2. **Lid/Roof:** Print with top surface on bed
3. **Legs:** Print vertically for layer strength
4. **Enclosures:** Print with open side up

### Post-Processing

1. **Sanding:** Smooth layer lines for better appearance
2. **Priming:** Use filler primer for painted finishes
3. **Sealing:** Apply waterproof sealant for outdoor use
4. **Threaded Inserts:** Use heat-set inserts for screw holes

---

## Assembly Notes

### Hardware Required

| Item | Quantity | Purpose |
|---|---|---|
| M3 screws (10mm) | 20 | General assembly |
| M3 screws (16mm) | 10 | Motor mounting |
| M3 nuts | 30 | Screw fastening |
| M3 threaded inserts | 15 | Plastic threads |
| Heat shrink tubing | - | Wire insulation |
| Zip ties | - | Cable management |

### Assembly Order

1. Print all parts and verify fit
2. Install threaded inserts in plastic parts
3. Mount motors to base chassis
4. Install electronics in enclosure
5. Attach enclosure to base
6. Route all cables
7. Attach legs/wheels
8. Install lid and roof
9. Final cable management

---

## Design Modifications

The `.stl files/` directory contains both original and resized versions:

- **Original files:** Standard dimensions as designed
- **Resized files:** Modified for specific component fit or printer calibration

If you need to modify the designs, the original CAD files should be used (not included in this repository).

---

## Troubleshooting

### Parts Don't Fit

1. Check printer calibration (XY dimensions)
2. Verify scale is 100% in slicer
3. Try the resized versions
4. Adjust tolerance in slicer settings

### Layer Separation

1. Increase extrusion temperature
2. Reduce cooling fan speed
3. Increase infill overlap
4. Use stronger material (PETG)

### Warping

1. Use heated bed
2. Apply adhesive (glue stick, hairspray)
3. Use brim or raft
4. Enclose printer

---

## File Archive

A compressed archive is also available:

| File | Description |
|---|---|
| `.stl files.rar` | Archive of all STL files |

---

*Document Version: 1.0*  
*Last Updated: February 2026*

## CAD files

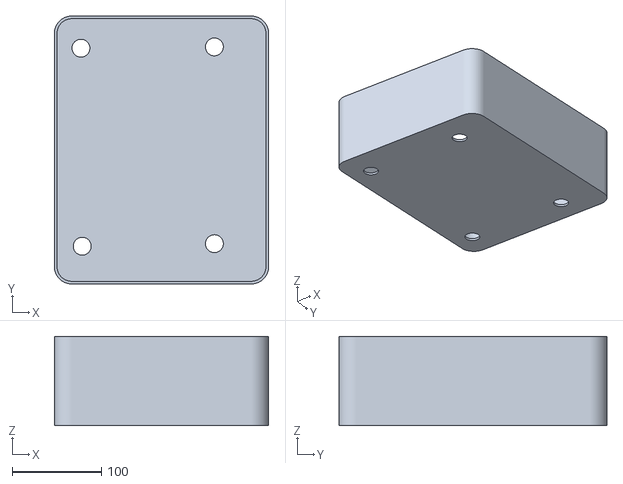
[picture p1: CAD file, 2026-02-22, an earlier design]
RoverProject/.stl files/base-Body.stl
240.0 x 300.0 x 100.0

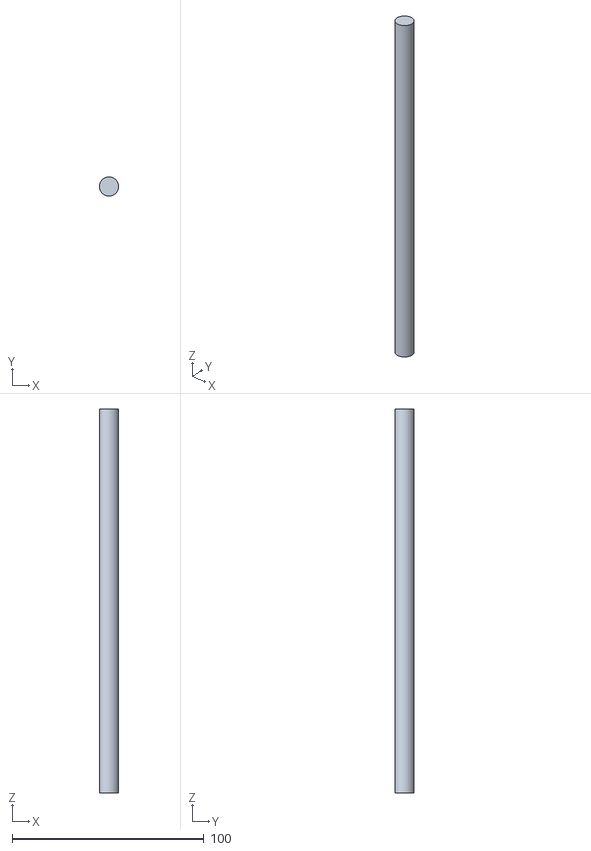
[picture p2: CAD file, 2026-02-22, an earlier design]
RoverProject/.stl files/short leg resized-Body.stl
10.0 x 10.00 x 200.0

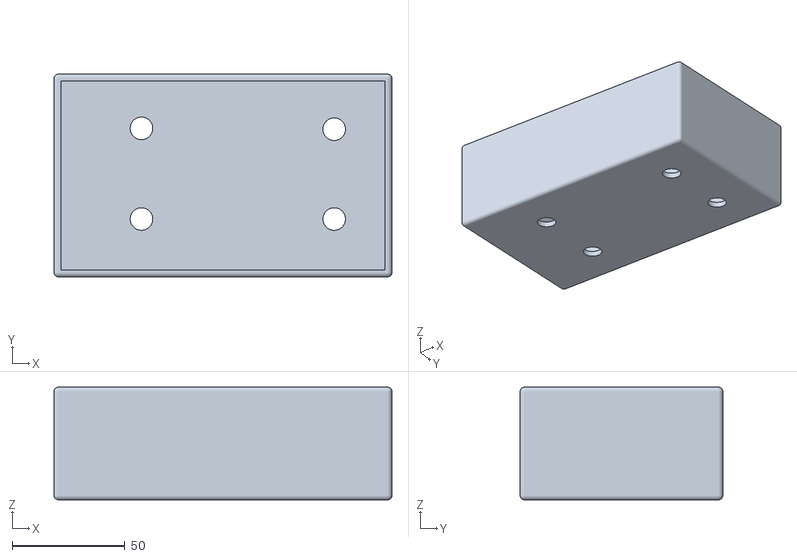
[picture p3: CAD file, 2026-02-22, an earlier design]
RoverProject/.stl files/base resized-Body.stl
150.0 x 90.0 x 50.0

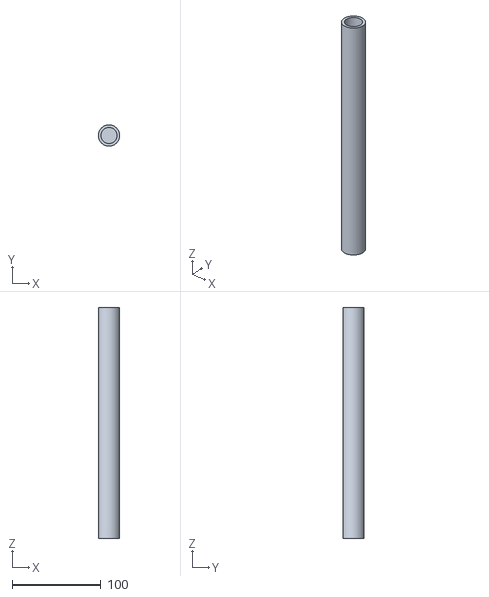
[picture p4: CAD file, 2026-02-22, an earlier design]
RoverProject/.stl files/long leg-Body.stl
24.0 x 24.0 x 260.0

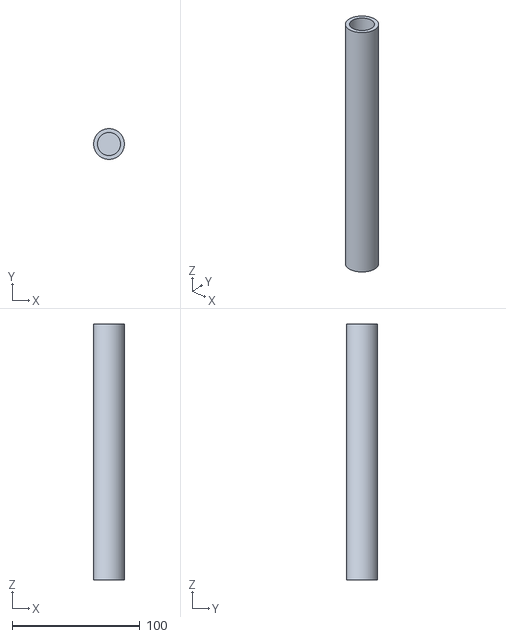
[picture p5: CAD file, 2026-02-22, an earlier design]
RoverProject/.stl files/short leg-Body.stl
24.0 x 24.0 x 200.0

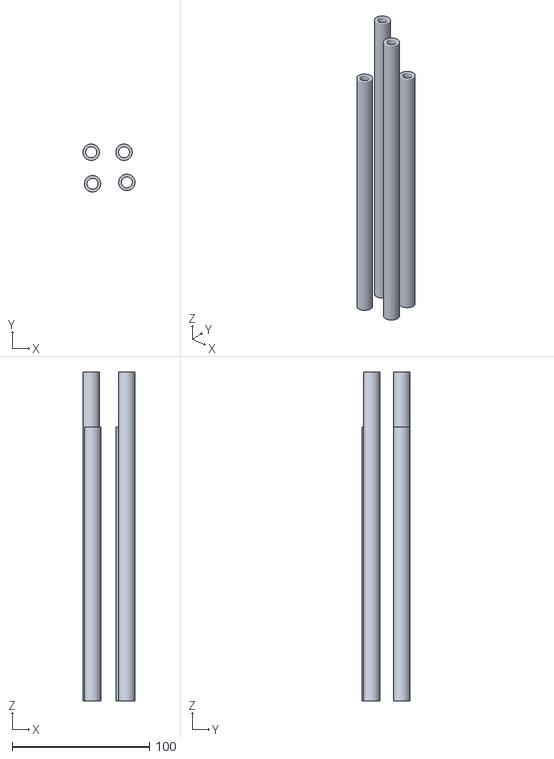
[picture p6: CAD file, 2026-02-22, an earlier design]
RoverProject/.stl files/legs resized.stl
38.0 x 35.0 x 240.0

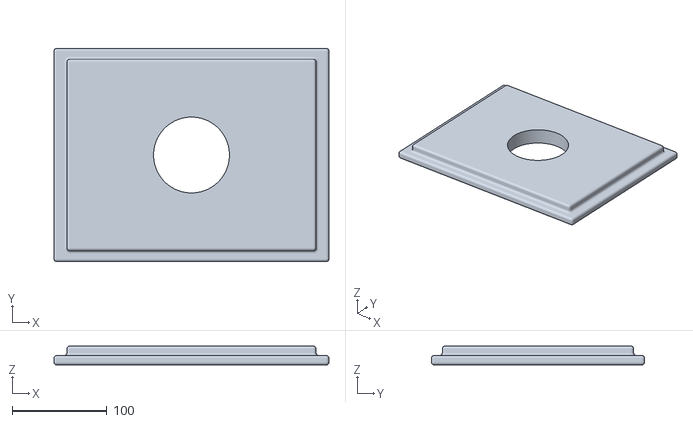
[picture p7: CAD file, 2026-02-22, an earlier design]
RoverProject/.stl files/lid-Body.stl
290.0 x 225.0 x 20.0

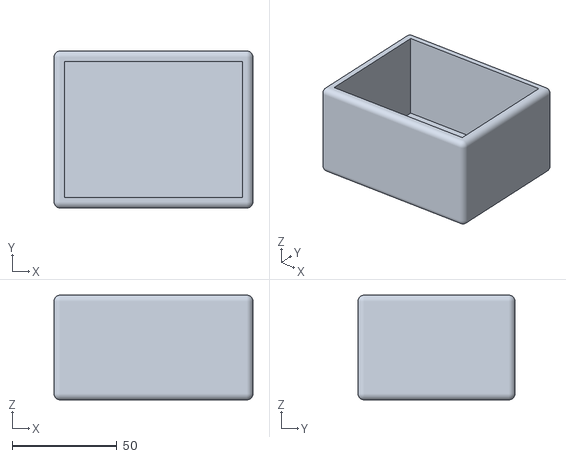
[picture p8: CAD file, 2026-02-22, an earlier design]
RoverProject/.stl files/file enclosure-Body.stl
95.0 x 75.0 x 50.0

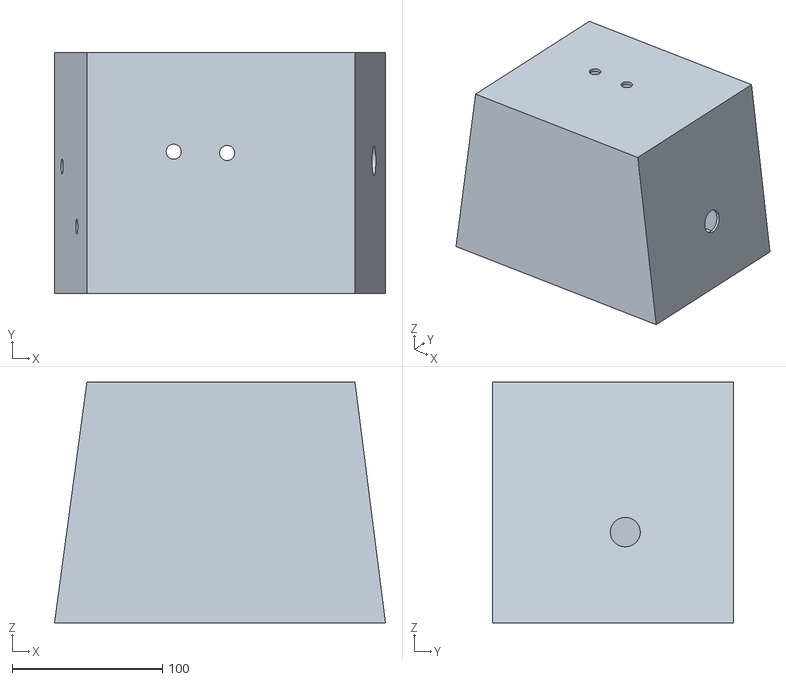
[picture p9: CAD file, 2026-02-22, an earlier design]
RoverProject/.stl files/roof-Body.stl
220.0 x 160.0 x 160.0

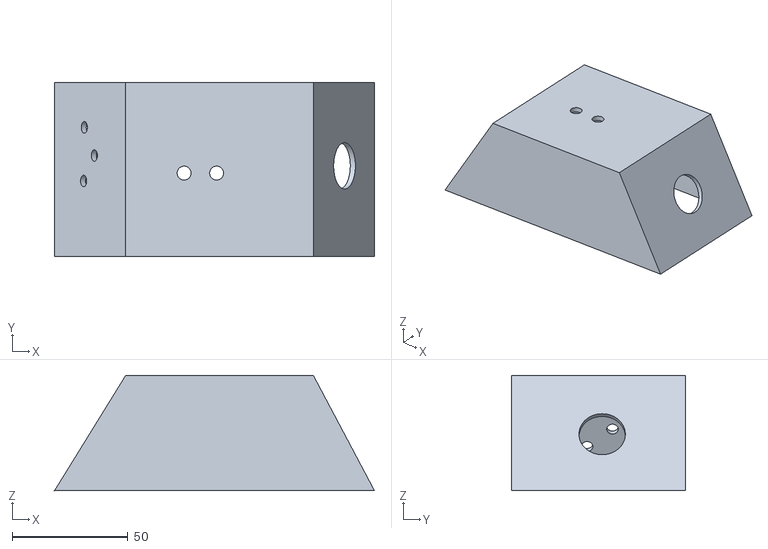
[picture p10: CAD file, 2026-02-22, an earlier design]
RoverProject/.stl files/roof resized-Body.stl
138.1 x 75.0 x 49.8

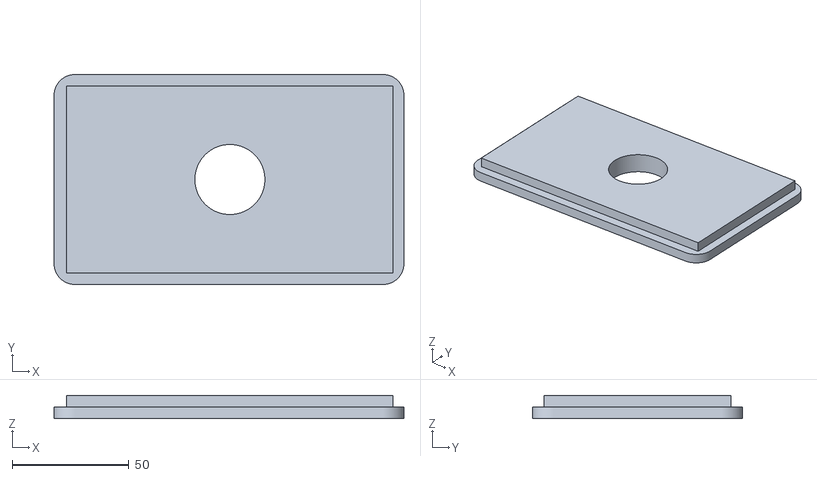
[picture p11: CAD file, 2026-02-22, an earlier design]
RoverProject/.stl files/lid resize-Body.stl
150.0 x 90.0 x 10.0

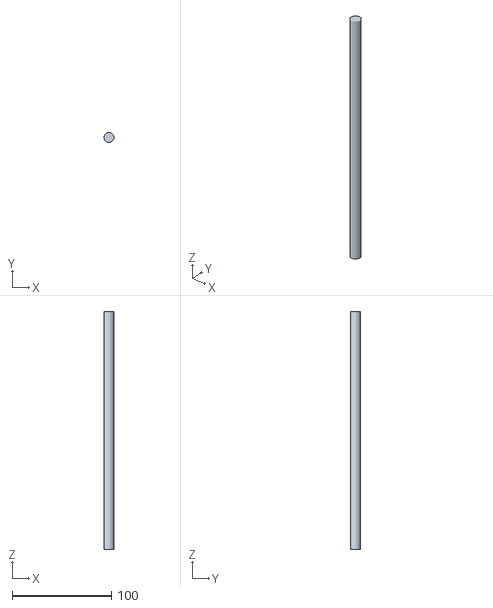
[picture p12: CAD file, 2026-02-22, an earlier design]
RoverProject/.stl files/Long leg resized-Body.stl
10.0 x 10.00 x 240.0

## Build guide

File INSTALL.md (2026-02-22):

# STASIS Autonomous Rover - Installation & Setup Guide

This guide covers the complete setup process for the STASIS autonomous environmental monitoring rover.

---

## Table of Contents

1. [Hardware Assembly](#hardware-assembly)
2. [Software Installation](#software-installation)
3. [Firmware Flashing](#firmware-flashing)
4. [Testing & Calibration](#testing--calibration)
5. [Operation](#operation)

---

## Hardware Assembly

### Required Components

#### Rover Unit
| Component | Model | Quantity |
|---|---|---|
| Main Controller | ESP32-S3 | 1 |
| Camera Module | ESP32-CAM | 1 |
| Motor Driver | L9110S | 1 |
| DC Motors | 6V-12V | 4 |
| Temperature Sensor | DS18B20 | 1 |
| Ultrasonic Sensor | HC-SR04 | 1 |
| IMU | MPU6050 | 1 |
| GPS Module | Neo-6M | 1 |
| GSM Module | SIM800L | 1 |
| Buzzer | 5V Active | 1 |
| Battery | LiPo 3S | 1 |

#### Base Station
| Component | Model | Quantity |
|---|---|---|
| Single Board Computer | Raspberry Pi Zero | 1 |
| Bridge Controller | ESP32-C3 | 1 |
| Camera | USB Webcam | 1 |
| Display | I2C LCD 16x2 | 1 |
| AprilTag | tag36h11 (200mm) | 1 |

### Wiring Connections

#### ESP32-S3 Pinout
```
GPIO4  → Motor A PWM
GPIO2  → Motor A Direction
GPIO5  → Motor B PWM
GPIO18 → Motor B Direction
GPIO6  → Motor C PWM
GPIO7  → Motor C Direction
GPIO15 → Motor D PWM
GPIO16 → Motor D Direction
GPIO10 → Ultrasonic Trig
GPIO9  → Ultrasonic Echo
GPIO14 → Buzzer
GPIO11 → DS18B20
```

#### L9110S Connection
```
Motor A: IA→GPIO4, IB→GPIO2
Motor B: IA→GPIO5, IB→GPIO18
Motor C: IA→GPIO6, IB→GPIO7
Motor D: IA→GPIO15, IB→GPIO16
```

---

## Software Installation

### Raspberry Pi Zero Setup

1. **Flash Raspberry Pi OS**
   ```bash
   # Download Raspberry Pi Imager
   # Select Raspberry Pi OS Lite (32-bit)
   # Enable SSH, set WiFi credentials
   ```

2. **Install Dependencies**
   ```bash
   sudo apt update
   sudo apt install -y python3-pip git
   pip3 install opencv-python numpy apriltag pyserial flask
   ```

3. **Configure Camera**
   ```bash
   sudo raspi-config
   # Interface Options → Camera → Enable
   # Reboot
   ```

### ESP32 Toolchain

1. **Install PlatformIO**
   ```bash
   # Linux/macOS
   pip3 install platformio
   
   # Windows
   pip install platformio
   ```

---

## Firmware Flashing

### 1. ESP32-CAM (Vision)

```bash
cd RoverProject/cam_firmware
pio run --target upload --environment esp32cam
```

### 2. ESP32-C3 (Base Bridge)

```bash
cd RoverProject/base_bridge
pio run --target upload --environment esp32-c3
```

### 3. ESP32-S3 (Main Controller)

```bash
cd RoverProject/rover_s3_firmware
pio run --target upload --environment esp32-s3
```

### 4. Raspberry Pi Zero

```bash
cd RoverProject/pi_zero_station
pip3 install -r requirements.txt

# Enable auto-start
sudo cp stasis.service /etc/systemd/system/
sudo systemctl enable stasis
sudo systemctl start stasis
```

---

## Testing & Calibration

### 1. Motor Test

```cpp
// In serial monitor, send commands:
F50    // Forward at 50%
B30    // Backward at 30%
L50    // Turn left
R50    // Turn right
S      // Stop
```

### 2. Sensor Test

```bash
# Run diagnostic script
python3 diagnostics.py
```

### 3. Camera Calibration

1. Print calibration checkerboard
2. Run:
   ```bash
   python3 calibrate_camera.py
   ```
3. Follow on-screen instructions

### 4. AprilTag Detection Test

```bash
python3 apriltag_docking.py --simulate
```

---

## Operation

### Starting the System

1. **Base Station**
   ```bash
   # Terminal 1: Start station monitor
   python3 station_monitor.py
   
   # Terminal 2: Start docking system (when needed)
   python3 apriltag_docking.py --device /dev/ttyUSB0
   ```

2. **Rover**
   - Power on battery
   - Wait for ESP-NOW connection (LED blink pattern)
   - System enters PATROL state

### State Transitions

```
PATROL → RESEARCH: Via API command
PATROL → ALERT: Fire/Human/Tilt detected
PATROL → RETURN_TO_BASE: Battery < 30%
PATROL → DOCKING: Docking enabled
```

### API Commands

```bash
# Get status
curl http://localhost:5000/api/status

# Send command
curl -X POST http://localhost:5000/api/command \
  -H "Content-Type: application/json" \
  -d '{"cmd": "RESEARCH"}'

# Enable docking
curl -X POST http://localhost:5000/api/command \
  -H "Content-Type: application/json" \
  -d '{"cmd": "DOCKING", "enabled": true}'
```

---

## Troubleshooting

### Common Issues

| Problem | Solution |
|---|---|
| No ESP-NOW connection | Check MAC addresses match |
| Camera not detected | Re-seat ribbon cable |
| Motors not moving | Verify L9110S power |
| GPS no fix | Ensure sky view, wait 5 min |
| Serial errors | Check TX/RX connections |

### LED Patterns

- **ESP32-S3**: 
  - Fast blink: Running
  - Slow blink: Error
  - Solid: Docked

- **ESP32-C3**:
  - 1 blink: Data RX
  - 2 blinks: Command TX
  - 3 blinks: Error

---

## Maintenance

### Battery Care
- Charge to 50% for storage
- Store in cool, dry location
- Check voltage monthly

### Cleaning
- Clean camera lens
- Remove debris from wheels
- Check sensor mounting

---

*Last Updated: February 2026*

This guide covers the complete setup process for the STASIS autonomous environmental monitoring rover.

---

## Table of Contents

1. [Hardware Assembly](#hardware-assembly)
2. [Software Installation](#software-installation)
3. [Firmware Flashing](#firmware-flashing)
4. [Testing & Calibration](#testing--calibration)
5. [Operation](#operation)

---

## Hardware Assembly

### Required Components

#### Rover Unit
| Component | Model | Quantity |
|---|---|---|
| Main Controller | ESP32-S3 | 1 |
| Camera Module | ESP32-CAM | 1 |
| Motor Driver | L9110S | 1 |
| DC Motors | 6V-12V | 4 |
| Temperature Sensor | DS18B20 | 1 |
| Ultrasonic Sensor | HC-SR04 | 1 |
| IMU | MPU6050 | 1 |
| GPS Module | Neo-6M | 1 |
| GSM Module | SIM800L | 1 |
| Buzzer | 5V Active | 1 |
| Battery | LiPo 3S | 1 |

#### Base Station
| Component | Model | Quantity |
|---|---|---|
| Single Board Computer | Raspberry Pi Zero | 1 |
| Bridge Controller | ESP32-C3 | 1 |
| Camera | USB Webcam | 1 |
| Display | I2C LCD 16x2 | 1 |
| AprilTag | tag36h11 (200mm) | 1 |

### Wiring Connections

#### ESP32-S3 Pinout
```
GPIO4  → Motor A PWM
GPIO2  → Motor A Direction
GPIO5  → Motor B PWM
GPIO18 → Motor B Direction
GPIO6  → Motor C PWM
GPIO7  → Motor C Direction
GPIO15 → Motor D PWM
GPIO16 → Motor D Direction
GPIO10 → Ultrasonic Trig
GPIO9  → Ultrasonic Echo
GPIO14 → Buzzer
GPIO11 → DS18B20
```

#### L9110S Connection
```
Motor A: IA→GPIO4, IB→GPIO2
Motor B: IA→GPIO5, IB→GPIO18
Motor C: IA→GPIO6, IB→GPIO7
Motor D: IA→GPIO15, IB→GPIO16
```

---

## Software Installation

### Raspberry Pi Zero Setup

1. **Flash Raspberry Pi OS**
   ```bash
   # Download Raspberry Pi Imager
   # Select Raspberry Pi OS Lite (32-bit)
   # Enable SSH, set WiFi credentials
   ```

2. **Install Dependencies**
   ```bash
   sudo apt update
   sudo apt install -y python3-pip git
   pip3 install opencv-python numpy apriltag pyserial flask
   ```

3. **Configure Camera**
   ```bash
   sudo raspi-config
   # Interface Options → Camera → Enable
   # Reboot
   ```

### ESP32 Toolchain

1. **Install PlatformIO**
   ```bash
   # Linux/macOS
   pip3 install platformio
   
   # Windows
   pip install platformio
   ```

---

## Firmware Flashing

### 1. ESP32-CAM (Vision)

```bash
cd RoverProject/cam_firmware
pio run --target upload --environment esp32cam
```

### 2. ESP32-C3 (Base Bridge)

```bash
cd RoverProject/base_bridge
pio run --target upload --environment esp32-c3
```

### 3. ESP32-S3 (Main Controller)

```bash
cd RoverProject/rover_s3_firmware
pio run --target upload --environment esp32-s3
```

### 4. Raspberry Pi Zero

```bash
cd RoverProject/pi_zero_station
pip3 install -r requirements.txt

# Enable auto-start
sudo cp stasis.service /etc/systemd/system/
sudo systemctl enable stasis
sudo systemctl start stasis
```

---

## Testing & Calibration

### 1. Motor Test

```cpp
// In serial monitor, send commands:
F50    // Forward at 50%
B30    // Backward at 30%
L50    // Turn left
R50    // Turn right
S      // Stop
```

### 2. Sensor Test

```bash
# Run diagnostic script
python3 diagnostics.py
```

### 3. Camera Calibration

1. Print calibration checkerboard
2. Run:
   ```bash
   python3 calibrate_camera.py
   ```
3. Follow on-screen instructions

### 4. AprilTag Detection Test

```bash
python3 apriltag_docking.py --simulate
```

---

## Operation

### Starting the System

1. **Base Station**
   ```bash
   # Terminal 1: Start station monitor
   python3 station_monitor.py
   
   # Terminal 2: Start docking system (when needed)
   python3 apriltag_docking.py --device /dev/ttyUSB0
   ```

2. **Rover**
   - Power on battery
   - Wait for ESP-NOW connection (LED blink pattern)
   - System enters PATROL state

### State Transitions

```
PATROL → RESEARCH: Via API command
PATROL → ALERT: Fire/Human/Tilt detected
PATROL → RETURN_TO_BASE: Battery < 30%
PATROL → DOCKING: Docking enabled
```

### API Commands

```bash
# Get status
curl http://localhost:5000/api/status

# Send command
curl -X POST http://localhost:5000/api/command \
  -H "Content-Type: application/json" \
  -d '{"cmd": "RESEARCH"}'

# Enable docking
curl -X POST http://localhost:5000/api/command \
  -H "Content-Type: application/json" \
  -d '{"cmd": "DOCKING", "enabled": true}'
```

---

## Troubleshooting

### Common Issues

| Problem | Solution |
|---|---|
| No ESP-NOW connection | Check MAC addresses match |
| Camera not detected | Re-seat ribbon cable |
| Motors not moving | Verify L9110S power |
| GPS no fix | Ensure sky view, wait 5 min |
| Serial errors | Check TX/RX connections |

### LED Patterns

- **ESP32-S3**: 
  - Fast blink: Running
  - Slow blink: Error
  - Solid: Docked

- **ESP32-C3**:
  - 1 blink: Data RX
  - 2 blinks: Command TX
  - 3 blinks: Error

---

## Maintenance

### Battery Care
- Charge to 50% for storage
- Store in cool, dry location
- Check voltage monthly

### Cleaning
- Clean camera lens
- Remove debris from wheels
- Check sensor mounting

---

*Last Updated: February 2026*

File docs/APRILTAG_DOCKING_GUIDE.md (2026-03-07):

# AprilTag Docking Guide

## Overview

STASIS uses AprilTag visual markers to guide the rover into precise contact with the charging dock. The Raspberry Pi Zero detects the tag from the ESP32-CAM's live stream and runs a proportional steering controller, sending binary commands to the rover in real time.

---

## How It Works

```
ESP32-CAM  →  MJPEG stream  →  Pi Zero (pupil-apriltags)
                                       │
                              Detect tag36h11 ID 0
                              Measure X error (px) and Z depth (m)
                                       │
                              Proportional controller:
                                turn  = clamp(err_x × 0.6, -100, +100)
                                speed = clamp(dist_m × 40, 10, 40)
                                dead-band: if |err_x| < 15 px → turn = 0
                                           if dist_m  < 0.25 m → DOCKED
                                       │
                              6-byte binary DockCommand
                              [0xAA | turn | speed | docked | XOR | 0x55]
                                       │
                              UART → ESP32-C3 → ESP-NOW → ESP32-S3 → motors
```

The docking thread in `station_monitor.py` starts automatically when the rover's telemetry reports `STATE_DOCKING`. It stops when the rover leaves that state or confirms a dock.

---

## Hardware Setup

### Tag Preparation

- **Family:** tag36h11
- **ID:** 0 (primary dock)
- **Printed size:** 10 cm × 10 cm minimum
- **Paper:** Matte, high contrast, black on white
- **Laminate** for durability and glare reduction
- **White border** of at least one tag-width around the printed marker

Download the tag image: https://github.com/AprilRobotics/apriltag-imgs

### Tag Placement

Mount the tag on the docking station face-on to the rover's approach path:

- Height: 20–40 cm from ground (centred with the camera)
- Angle: perpendicular to the approach — do not tilt the tag
- Lighting: ensure consistent, direct light — avoid backlighting

### Camera Mounting

The ESP32-CAM should be mounted at the front of the rover:

- Facing forward, level with the tag height when the rover is at the dock
- Fixed — no flex or vibration in the mount
- Unobstructed field of view

---

## Software Setup

### Install dependencies (Pi Zero, once)

```bash
pip install pupil-apriltags opencv-python-headless
```

### Set the camera stream URL

The docking thread reads `CAM_STREAM_URL` from the environment. Set it in the systemd service or shell:

```bash
export CAM_STREAM_URL=http://192.168.4.1:81/stream
```

Default if not set: `http://192.168.4.1:81/stream`

### Verify the stream is reachable

```bash
curl -I http://192.168.4.1:81/stream
# Should return HTTP/1.1 200 OK
```

---

## Configuration Parameters

These constants are near the top of the AprilTag section in `station_monitor.py`:

| Constant | Default | Description |
|---|---|---|
| `APRILTAG_ID` | 0 | Tag ID to dock to |
| `APRILTAG_SIZE_M` | 0.10 | Physical tag side length in metres |
| `CAM_FX`, `CAM_FY` | 320.0 | Camera focal length in pixels |
| `CAM_CX`, `CAM_CY` | 160.0, 120.0 | Principal point (QVGA centre) |
| `DOCK_CENTRE_TOL` | 15 | X dead-band in pixels before steering |
| `DOCK_CLOSE_DIST` | 0.25 | Distance in metres to declare docked |

> **Calibrating focal length:** For accurate distance estimation, measure the tag at a known distance and adjust `CAM_FX`/`CAM_FY` so the reported Z depth matches reality.

---

## Docking Sequence

### Phase 1 — Command
Send `DOCKING` command from dashboard or API. Rover transitions to `STATE_DOCKING`.

### Phase 2 — Search
If the tag is not immediately visible, the rover rotates slowly (turn=30, speed=15) until the tag enters the camera frame.

### Phase 3 — Approach
Once the tag is detected:
- Steering corrects X alignment proportionally
- Speed decreases as distance closes
- Dead-band of ±15 px prevents steering oscillation when nearly centred

### Phase 4 — Contact
When `dist_m < 0.25 m`, a final `docked=1` packet is sent to halt the rover. The rover's dock detection (battery voltage rise) confirms actual electrical contact and transitions to `STATE_DOCKED_CHARGING`.

---

## Dashboard Integration

When the docking thread detects a tag, it emits a Socket.IO event to all connected dashboard clients:

```json
{ "found": true,  "tag_id": 0, "err_x": -12.3, "dist_m": 0.87 }
{ "found": false }
```

The dashboard displays docking status in real time on the Dashboard and Map panels.

---

## Troubleshooting

| Problem | Cause | Fix |
|---|---|-----|
| Tag never detected | Poor lighting or tag too small | Improve lighting; check 10 cm print size |
| Rover oscillates left/right | Dead-band too small | Increase `DOCK_CENTRE_TOL` from 15 to 25 |
| Rover overshoots the dock | Speed too high near contact | Decrease the speed multiplier (`dist_m × 40`) |
| Wrong distance reported | Focal length not calibrated | Measure actual distance vs reported; scale `CAM_FX`/`CAM_FY` |
| `APRILTAG_AVAILABLE = False` | Library not installed | `pip install pupil-apriltags opencv-python-headless` |
| Camera stream not opening | Wrong IP or ESP32-CAM offline | Verify `CAM_STREAM_URL`; check camera AP is up |
| Docking thread doesn't activate | Rover not in DOCKING state | Check telemetry `status` field contains `DOCKING` |

---

## Testing Without the Rover

Print the tag and hold it in front of the camera at arm's length. Watch the Pi logs:

```
AprilTag: rover in DOCKING state — opening camera stream
AprilTag: id=0 err_x=23.5 dist=0.94m
AprilTag: id=0 err_x=2.1  dist=0.41m
AprilTag: DOCKED (dist=0.22m) — stopping motors
```

You can also monitor the dashboard's Socket.IO `apriltag` events in the browser console.

---

*Last updated: March 2026 — v2*

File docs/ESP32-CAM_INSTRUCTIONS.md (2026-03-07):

# ESP32-CAM — Vision Module

## Overview

The ESP32-CAM provides vision capabilities for the STASIS rover:

- Fire detection (RGB colour analysis)
- Motion detection (frame differencing)
- Human detection (skin-tone heuristic)
- MJPEG streaming for AprilTag processing on the Pi

All hazard output is **plain text only** — no binary structs are written to Serial.

---

## Hardware

- **Board:** AI Thinker ESP32-CAM
- **Camera:** OV2640, QVGA (320×240), RGB565
- **Serial:** UART0 (`U0T`/`U0R`) — no native USB, requires FTDI programmer for flashing
- **Status LED:** GPIO 4 (active low)

---

## Flashing

### Wiring (FTDI programmer required)

| ESP32-CAM | FTDI Programmer |
|---|---|
| U0R (RX) | TX |
| U0T (TX) | RX |
| GND | GND |
| 5V | 5V |
| **IO0** | **GND** ← Flash mode only |

### Steps

1. Connect IO0 → GND
2. Open `cam_firmware/cam_firmware.ino` in Arduino IDE
3. Board: **AI Thinker ESP32-CAM** | Upload speed: **115200**
4. Click Upload
5. Wait for "Done uploading"
6. **Disconnect IO0 from GND**
7. Press RST or power-cycle

### Verify

Open Serial Monitor at 115200 baud. You should see: `CAM:READY`

If you see `CAM:ERROR`, reseat the camera ribbon cable (contacts face down).

---

## Pin Reference

| ESP32-CAM | ESP32-S3 | Function |
|---|---|---|
| U0T (TX) | Serial RX (cameraTask) | Hazard text messages |
| U0R (RX) | Serial TX | Command bytes |
| 5V | 5V rail | Power |
| GND | GND | Ground |

---

## Commands (from ESP32-S3)

Single-byte commands:

| Byte | Name | Effect |
|---|---|---|
| `0x01` | CAPTURE | Capture one frame, run detection, return result |
| `0x02` | STREAM_ON | Start continuous MJPEG stream |
| `0x03` | STREAM_OFF | Stop streaming |
| `0x04` | DETECT | Run detection only (no stream) |
| `0x05` | APRIL_STREAM | Switch to JPEG mode and start streaming (AprilTag) |

---

## Output Messages (to ESP32-S3)

All output is plain text, one message per line:

| Message | Meaning |
|---|---|
| `CAM:READY` | Camera initialised |
| `CAM:ERROR` | Camera failed to initialise |
| `HAZARD:FIRE` | Fire pixels detected |
| `HAZARD:MOTION` | Motion detected |
| `HAZARD:HUMAN` | Human detected |
| `CLEAR` | No hazards in current frame |

> **v2 change:** Raw binary `DetectionResult` struct writes were removed from `captureAndSend()` and `detectOnly()`. The binary bytes were corrupting the S3's text-line parser. Text-only output is unambiguous and sufficient.

---

## Detection Algorithm

The camera processes every Nth pixel (sample step = 50) in RGB565 format.

**Fire detection** — looks for high red, moderate green, low blue:
```
R > 25  AND  G > 10  AND  B < 8
→ fire pixel confirmed
→ trigger if firePixels > 15
```

**Motion detection** — compares against downsampled previous frame:
```
|current_pixel - previous_pixel| > 4000
→ motion pixel confirmed
→ trigger if motionPixels > 30
```

**Human detection** — skin tone heuristic in RGB565 5/6/5 bit space:
```
R > 15  AND  8 < G < 20  AND  5 < B < 15
→ human pixel confirmed
→ trigger if humanPixels > 30  (higher threshold than fire)
```

---

## Camera Settings

| Setting | Value | Reason |
|---|---|---|
| Frame size | QVGA (320×240) | Fast processing on ESP32-CAM |
| Pixel format | RGB565 | Efficient for colour analysis |
| Frame buffers | 2 | Double-buffered for streaming |
| XCLK | 20 MHz | Standard speed |

---

## Streaming for AprilTag

When `CMD_APRIL_STREAM (0x05)` is sent, the camera switches to JPEG format and starts streaming. The Pi Zero reads this MJPEG stream at `CAM_STREAM_URL` for AprilTag detection.

The default stream endpoint served by the ESP32-CAM: `http://192.168.4.1:81/stream`

---

## LED Behaviour

| Pattern | Meaning |
|---|---|
| 3 quick blinks at boot | Starting up |
| Solid 500 ms | Camera ready |
| Continuous fast blink | Camera error |
| Brief flash on capture | Capture in progress |

---

## Troubleshooting

| Problem | Fix |
|---|-----|
| `CAM:ERROR` | Reseat ribbon cable; contacts must face down toward board |
| Upload fails | Ensure IO0 is grounded; try different baud rate |
| Brownout during flash | Use a 100 µF capacitor between 5V and GND |
| Poor detection | Improve lighting; adjust detection thresholds in firmware |
| MJPEG stream not opening | Check AP connection; verify `http://192.168.4.1:81/stream` |

---

*Last updated: March 2026 — v2*

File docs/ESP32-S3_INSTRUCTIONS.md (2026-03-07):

# ESP32-S3 — Rover Main Controller

## Overview

The ESP32-S3 is the brain of the STASIS rover. It runs a FreeRTOS multi-task firmware that handles the state machine, motor control, sensor fusion, GPS geofencing, dock detection, and GSM alerts.

---

## Board Setup (Arduino IDE)

1. **File → Preferences → Additional Boards Manager URLs:**
   ```
   https://raw.githubusercontent.com/espressif/arduino-esp32/gh-pages/package_esp32_index.json
   ```
2. **Tools → Board → Boards Manager** → install `esp32 by Espressif Systems`
3. **Tools → Board → ESP32 Arduino → ESP32S3 Dev Module**

| Setting | Value |
|---|---|
| Upload Speed | 921600 |
| USB CDC on Boot | Enabled |
| CPU Frequency | 240 MHz |
| Flash Size | 4 MB |
| Partition Scheme | Default 4 MB with spiffs |

---

## Required Libraries

Install via Library Manager:

| Library | Purpose |
|---|---|
| TinyGPSPlus | NMEA GPS parsing (optional, custom parser also included) |
| OneWire | DS18B20 temperature sensor |
| DallasTemperature | DS18B20 high-level API |

---

## Uploading

1. Open `rover_main/rover_main.ino`
2. Connect ESP32-S3 via USB-C
3. Select the correct COM port
4. Click **Upload**

> If upload fails, hold the **BOOT** button, click Upload, release BOOT when "Connecting..." appears.

---

## Pin Assignments

| GPIO | Function | Connected To | Notes |
|---|---|---|---|
| 1 | Battery ADC | 30k/10k divider | Reads pack voltage |
| 2 | Motor A DIR | L9110S | |
| 4 | Motor A PWM | L9110S | LEDC channel |
| 5 | Motor B PWM | L9110S | LEDC channel |
| 6 | Motor C PWM | L9110S | LEDC channel |
| 7 | Motor C DIR | L9110S | |
| 8 | GPS Serial2 RX | NEO-6M TX | Hardware Serial2 |
| 9 | Ultrasonic ECHO | HC-SR04 | |
| 10 | Ultrasonic TRIG | HC-SR04 | |
| 12 | SIM800 RX | SIM800L TXD | **Serial1** |
| 13 | SIM800 TX | SIM800L RXD | **Serial1** |
| 14 | Buzzer | Active buzzer | |
| 15 | Motor D PWM | L9110S | LEDC channel |
| 16 | Motor D DIR | L9110S | |
| 18 | Motor B DIR | L9110S | |
| 19 | GPS Serial2 TX | NEO-6M RX | Hardware Serial2 |
| 21 | DS18B20 | OneWire data | 4.7 kΩ pull-up to 3.3 V |
| 43 | UART1 TX | Pi Zero (via C3) | |
| 44 | UART1 RX | Pi Zero (via C3) | |
| 45 | Status LED | — | |

> **Serial port assignment:**
> GPS (NEO-6M) → **Serial2** on pins 8, 19.
> SIM800L → **Serial1** on pins 12, 13.
> These are separate hardware UARTs and do not conflict.

---

## State Machine

| State | Behaviour |
|---|---|
| `SAFE_IDLE` | Motors off. Sensors active. Waits for command. |
| `PATROL` | Drives forward at patrol speed. Monitors geofence, hazards, and obstacles. |
| `ALERT` | Motors stop. Buzzer sounds. SMS sent. Waits for confirmation or timeout. |
| `RETURN_TO_BASE` | Drives toward home GPS coordinates. |
| `DOCKING` | Receives binary `DockCommand` packets from Pi via UART and applies turn/speed directly. |
| `DOCKED_CHARGING` | Motors fully disabled. Battery and temperature monitored. |

All transitions use `millis()` — no `delay()` in any state path.

---

## Commands (via UART from Pi)

| Command | Effect |
|---|---|
| `STOP` | → SAFE_IDLE, speed = 0 |
| `FORWARD` | speed = 50 forward |
| `BACKWARD` | speed = 50 reverse |
| `LEFT` | turn = −50, speed = 30 |
| `RIGHT` | turn = +50, speed = 30 |
| `PATROL` | → PATROL state |
| `STOP_PATROL` | → SAFE_IDLE |
| `HOME` / `RETURN_BASE` | → RETURN_TO_BASE |
| `DOCKING` | → DOCKING state |
| `DISABLE_DOCKING` | → SAFE_IDLE |
| `SETHOME` | Save current GPS as home (requires valid fix) |
| `RESET` | Reset all flags, → SAFE_IDLE |

---

## Docking Binary Packet (Pi → Rover)

During `STATE_DOCKING`, the Pi sends 6-byte binary packets over UART:

```
Byte 0: 0xAA       (header)
Byte 1: turn       (int8, -100 to +100)
Byte 2: speed      (uint8, 0-100)
Byte 3: docked     (uint8, 0 or 1)
Byte 4: checksum   (XOR of bytes 1, 2, 3)
Byte 5: 0x55       (tail)
```

The rover's `uartTask` uses a `binaryMode` flag to collect all 6 bytes before parsing. Text commands cannot be mixed with binary packets mid-stream.

---

## Key Configuration Constants

```cpp
// Timeouts
#define COMMAND_TIMEOUT_MS    500     // Stop if no dock command for 500 ms
#define GPS_VALID_AGE_MS      10000   // Discard GPS fixes older than 10 s
#define GPS_STARTUP_GRACE_MS  90000   // Don't GPS-halt for first 90 s (cold start)

// Dock detection
#define DOCK_VOLTAGE_RISE     0.4     // Volts above baseline to confirm dock
#define DOCK_DEBOUNCE_FRAMES  20      // Frames (~2 s at 100 ms/frame)

// Geofence
#define GEOFENCE_RADIUS_M     50.0    // Metres from home

// Battery
#define LOW_BATTERY_THRESHOLD 20      // % — triggers low-power mode
#define LOW_BATTERY_VOLTAGE   6.2     // V — hard shutdown
#define CHARGE_COMPLETE_VOLTAGE 8.4   // V — full cell voltage (2S)

// GSM
#define SMS_COOLDOWN_MS       60000   // One SMS per 60 s maximum

// Motor
#define SPEED_RAMP_RATE       5       // PWM units per control cycle
```

---

## FreeRTOS Task Layout

| Task | Core | Priority | Stack | Responsibility |
|---|---|---|---|---|
| `uartTask` | 0 | 2 | 3072 | Receive commands and dock packets from Pi |
| `cameraTask` | 1 | 1 | 3072 | Forward ESP32-CAM hazard messages to Pi |
| `sensorTask` | 1 | 1 | 4096 | Ultrasonic, temperature, LDR, battery, GSM |
| `gpsTask` | 1 | 1 | 3072 | NMEA parsing, geofence updates |
| `stateTask` | 1 | 1 | 3072 | State machine transitions and motor execution |

---

## Serial Monitor Output

Connect at **115200 baud** to see:

```
STASIS Rover Initializing...
DOCK: Baseline established at 7.41V
GEOFENCE: Home set to 12.345678, 77.123456
State: 1                          ← state enum value
GPS: No fix - SAFE_HALT           ← if GPS lost
DOCK: Confirmed at 7.83V (rise: 0.42V)
CHARGING: Voltage=7.83V, Started=YES
```

---

## Troubleshooting

| Symptom | Likely Cause | Fix |
|---|---|-----|
| Rover doesn't stop on STOP command | `estop()` broken | Ensure `ledcWrite` used, not `digitalWrite` |
| BACKWARD drives forward | Old bug (fixed in v2) | Flash latest firmware |
| GPS halts rover immediately on boot | Startup grace missing | Flash latest firmware (90 s grace added) |
| SMS sends but GPS is garbled | Serial2 conflict | Check SIM800 is on Serial1, GPS on Serial2 |
| Docking doesn't steer | Binary packet parser | Check `binaryMode` flag present in `uartTask` |
| Stack overflow crash | Task stack too small | Ensure stacks are 3072 / 4096 as set |

---

*Last updated: March 2026 — v2*

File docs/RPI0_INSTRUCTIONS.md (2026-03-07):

# Raspberry Pi Zero — Base Station Setup

## Overview

The Pi Zero runs `station_monitor.py`, which handles:
- Reading JSON telemetry from the ESP32-C3 bridge over UART
- Serving the REST API and web dashboard on port 5000
- Storing telemetry in a SQLite database
- Generating PDF mission reports when the rover docks
- Running the AprilTag visual docking control loop

---

## OS Setup

### 1. Flash Raspberry Pi OS Lite

Use **Raspberry Pi Imager** (https://www.raspberrypi.com/software/):

- OS: **Raspberry Pi OS Lite (32-bit)**
- Click the gear icon before writing to pre-configure:
  - Hostname: `stasis-base`
  - Enable SSH: Yes
  - Username / password: `pi` / `sentinel2024`
  - Locale: your timezone

### 2. Enable the serial port (disable serial console)

```bash
sudo raspi-config
# Interface Options → Serial Port
#   Login shell over serial: No
#   Serial port hardware enabled: Yes
# Reboot
```

---

## Install Dependencies

```bash
sudo apt update
sudo apt install -y python3-pip

# Core station monitor
pip install flask flask-cors flask-socketio pyserial fpdf2 eventlet

# AprilTag docking (optional but recommended)
pip install pupil-apriltags opencv-python-headless

# Cache Leaflet maps for offline use (run once with internet access)
mkdir -p ~/stasis/static
wget -O ~/stasis/static/leaflet.css https://unpkg.com/leaflet@1.9.4/dist/leaflet.css
wget -O ~/stasis/static/leaflet.js  https://unpkg.com/leaflet@1.9.4/dist/leaflet.js
```

---

## Copy the Project

```bash
# From your computer (replace with actual path)
scp -r STASIS/ pi@stasis-base.local:~/stasis/
```

---

## Auto-Start with systemd

```bash
sudo nano /etc/systemd/system/stasis.service
```

```ini
[Unit]
Description=STASIS Base Station Monitor
After=network.target

[Service]
Type=simple
User=pi
WorkingDirectory=/home/pi/stasis
ExecStart=/usr/bin/python3 /home/pi/stasis/base_station/station_monitor.py
Restart=always
RestartSec=10
StandardOutput=journal
StandardError=journal

Environment="SERIAL_PORT=/dev/serial0"
Environment="BAUD_RATE=115200"
Environment="FLASK_HOST=0.0.0.0"
Environment="FLASK_PORT=5000"
Environment="CAM_STREAM_URL=http://192.168.4.1:81/stream"

[Install]
WantedBy=multi-user.target
```

```bash
sudo systemctl daemon-reload
sudo systemctl enable stasis
sudo systemctl start stasis
```

---

## Wiring (ESP32-C3 → Pi Zero)

| ESP32-C3 | Raspberry Pi Zero | Function |
|---|---|---|
| GPIO 21 (TX) | Pin 10 (GPIO 15 / RXD) | UART data to Pi |
| GPIO 20 (RX) | Pin 8 (GPIO 14 / TXD) | UART data from Pi |
| 5V | Pin 2 (5V) | Power from Pi |
| GND | Pin 6 (GND) | Common ground |

> Only the bottom row of the Pi GPIO header is used (even-numbered pins: 2, 4, 6, 8, 10).

---

## Testing

### Verify serial comms

```bash
sudo apt install minicom
minicom -D /dev/serial0 -b 115200
# Should see JSON telemetry lines scrolling
# Press Ctrl+A then X to exit
```

### Verify the API

```bash
# Public health check
curl http://localhost:5000/api/health

# Authenticated status
curl -H "X-API-Key: stasis-2024" http://localhost:5000/api/status
```

### Access the dashboard

Connect to the `Stasis-Base` WiFi AP, then open:
```
http://192.168.4.1:5000/stasis_app/index.html
```

### Check service logs

```bash
journalctl -u stasis -f
```

### Send a test command

```bash
curl -X POST http://localhost:5000/api/command \
  -H "Content-Type: application/json" \
  -H "X-API-Key: stasis-2024" \
  -d '{"cmd": "STOP"}'
```

---

## Boot Sequence

1. Pi OS boots (~30–60 s)
2. `stasis.service` starts automatically
3. Serial listener thread opens `/dev/serial0`
4. Flask API starts on `0.0.0.0:5000`
5. AprilTag thread starts (waits for `STATE_DOCKING` telemetry)
6. Dashboard is accessible from any device on `Stasis-Base` WiFi

---

## Troubleshooting

| Problem | Fix |
|---|-----|
| `/dev/serial0` not found | Run `raspi-config` → Interface Options → Serial Port → disable login shell, enable hardware |
| Permission denied on serial | `sudo usermod -a -G dialout pi` then logout/login |
| Service not starting | `journalctl -u stasis -n 50` to see the error |
| AprilTag thread disabled | `pip install pupil-apriltags opencv-python-headless` |
| Camera stream not opening | Check `CAM_STREAM_URL` in service env; verify ESP32-CAM is on AP |
| Dashboard map broken | Run the Leaflet cache `wget` commands (needs internet once) |

---

*Last updated: March 2026 — v2*

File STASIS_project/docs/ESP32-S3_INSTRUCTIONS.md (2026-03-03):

# ESP32-S3 Rover Main Controller - Firmware Guide

## Overview

The ESP32-S3 is the main controller for the STASIS rover. It handles:
- State machine control (PATROL, ALERT, RETURN_TO_BASE, DOCKING, DOCKED_CHARGING, SAFE_IDLE)
- Motor control (L9110S 4WD)
- Sensor fusion (ultrasonic, temperature, GPS)
- Dock detection via battery voltage rise
- GPS geofence monitoring
- GSM alert triggering via SIM800
- Communication with Raspberry Pi via UART

---

## Hardware

### Board
- ESP32-S3 Dev Module
- USB-C for programming

### Pin Assignments

| Function | GPIO | Notes |
|---|---|---|
| Motor A PWM | 4 | L9110S |
| Motor A DIR | 2 | L9110S |
| Motor B PWM | 5 | L9110S |
| Motor B DIR | 18 | L9110S |
| Motor C PWM | 6 | L9110S |
| Motor C DIR | 7 | L9110S |
| Motor D PWM | 15 | L9110S |
| Motor D DIR | 16 | L9110S |
| Ultrasonic TRIG | 10 | HC-SR04 |
| Ultrasonic ECHO | 9 | HC-SR04 |
| GPS TX | 8 | NEO-6M |
| GPS RX | 19 | NEO-6M |
| SIM800 TX | 13 | |
| SIM800 RX | 12 | |
| Buzzer | 14 | |
| Status LED | 45 | |
| Battery ADC | 1 | Via voltage divider |

---

## State Machine

```
SAFE_IDLE ←→ PATROL ←→ ALERT
                ↓
        RETURN_TO_BASE
                ↓
           DOCKING ←→ DOCKED_CHARGING
```

### States

| State | Description |
|---|---|
| SAFE_IDLE | Minimal power, waiting for commands |
| PATROL | Autonomous patrol with geofence |
| ALERT | Hazard detected, investigating |
| RETURN_TO_BASE | Geofence breach or manual recall |
| DOCKING | AprilTag precision approach |
| DOCKED_CHARGING | Passive charging, motors disabled |

---

## Commands

Send via UART from Raspberry Pi:

| Command | Action |
|---|---|
| `STOP` | Emergency stop → SAFE_IDLE |
| `FORWARD` | Move forward |
| `BACKWARD` | Move backward |
| `LEFT` | Turn left |
| `RIGHT` | Turn right |
| `PATROL` | Start autonomous patrol |
| `STOP_PATROL` | Stop patrol → SAFE_IDLE |
| `HOME` / `RETURN_BASE` | Return to base |
| `DOCKING` | Enable docking mode |
| `DISABLE_DOCKING` | Disable docking |
| `SETHOME` | Set current GPS as home |
| `RESET` | Reset all states |

---

## Safety Features

### Dock Detection
- Monitors battery voltage rise (charging)
- Requires 0.4V above baseline sustained for 2 seconds
- 20-frame debounce to prevent chatter

### GPS Geofence
- 50m radius from home position
- Ignores invalid coordinates (0.0, 0.0)
- SAFE_HALT if GPS older than 5 seconds

### SIM800 Protection
- Motors stop before SMS to prevent brownout
- 60-second cooldown between SMS
- Non-blocking operation

### Ultrasonic
- Non-blocking with 30ms timeout
- Default 999cm when no reading

---

## Configuration Constants

```cpp
// Timeout
#define COMMAND_TIMEOUT_MS  500

// Dock Detection
#define DOCK_VOLTAGE_RISE      0.4    // Volts
#define DOCK_CONFIRM_TIME_MS   2000   // ms
#define DOCK_DEBOUNCE_FRAMES  20

// Geofence
#define GEOFENCE_RADIUS_M   50.0    // meters
#define GPS_VALID_AGE_MS   10000    // ms

// Battery
#define LOW_BATTERY_THRESHOLD 30.0   // percent
#define LOW_BATTERY_VOLTAGE   6.2    // volts (2S cutoff)

// GSM
#define SMS_COOLDOWN_MS 60000  // 60 seconds
```

---

## Uploading

1. Open `rover_main/rover_main.ino` in Arduino IDE
2. Select ESP32S3 Dev Module
3. Set baud to 921600
4. Hold BOOT button while uploading if needed

---

## Serial Output

Monitor at 115200 baud to see:
- State transitions
- GPS coordinates
- Battery voltage
- Dock detection events
- Alert triggers

---

*Last Updated: March 2026*

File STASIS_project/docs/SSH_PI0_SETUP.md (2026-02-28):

# SSH into Raspberry Pi Zero - Wired Connection Guide

This guide covers how to SSH into your Raspberry Pi Zero from your computer using a wired USB connection (no WiFi required).

---

## Method 1: USB Ethernet (Recommended)

This method uses the Pi's Micro-USB port to create an Ethernet over USB connection.

### On Raspberry Pi Zero (One-Time Setup)

1. **Enable Ethernet over USB:**
   
   Add these lines to `/boot/config.txt` (on the SD card):
   ```
   dtoverlay=dwc2
   ```
   
   Add this to `/boot/cmdline.txt` after `rootwait`:
   ```
   modules=loop,snd-usb-audio,dwc2,g_ether
   ```

2. **Enable SSH:**
   
   Create an empty file named `ssh` in the boot partition:
   ```
   touch /boot/ssh
   ```

3. **Set a static hostname (optional):**
   
   Edit `/etc/hostname`:
   ```
   stasis-base
   ```

4. **Set up a username/password:**
   
   The default is `pi` / `raspberry`. Change it:
   ```bash
   sudo raspi-config
   # System Options → Password
   ```

### On Your Computer

#### Windows:
1. Install RNDIS/Ethernet gadget driver:
   - Download from: https://github.com/pbatard/libwdi/wiki/USB-RNDIS-Drivers
   - Or use Zadig: https://zadig.akeo.ie/

2. Connect USB cable to **USB** port (not PWR) on Pi Zero

3. Wait for "USB Ethernet/RNDIS" to appear in Network Adapters

4. SSH using:
   ```
   ssh pi@raspberrypi.local
   ```
   Or if you set a hostname:
   ```
   ssh pi@stasis-base.local
   ```

#### macOS:
1. Connect USB cable to **USB** port (not PWR) on Pi Zero

2. Open Terminal and SSH:
   ```bash
   ssh pi@raspberrypi.local
   ```
   Or:
   ```bash
   ssh pi@stasis-base.local
   ```

#### Linux:
1. Connect USB cable to **USB** port (not PWR) on Pi Zero

2. SSH:
   ```bash
   ssh pi@raspberrypi.local
   ```

---

## Method 2: Serial Console (TTL Adapter)

If you have a USB-to-TTL adapter (like FTDI), you can access the Pi's console.

### Wiring

| USB-TTL Adapter | Raspberry Pi Zero |
|---|---|
| RX (Green) | Pin 8 (TXD/GPIO 14) |
| TX (White) | Pin 10 (RXD/GPIO 15) |
| 5V (Red) | Pin 2 or 4 (5V) - **ONLY IF POWERING FROM ADAPTER** |
| GND (Black) | Pin 6 (GND) |

**⚠️ IMPORTANT: Don't connect 5V if Pi is powered separately!**

### Connection

1. Connect adapter to your computer
2. Use a terminal program:
   - **Windows:** PuTTY, set COM port at 115200 baud
   - **macOS/Linux:** 
     ```bash
     screen /dev/ttyUSB0 115200
     ```
     Or:
     ```bash
     minicom -D /dev/ttyUSB0 -b 115200
     ```

3. Login with: `pi` / `raspberry`

---

## Method 3: Ethernet Hat / USB Hub

If you have an Ethernet USB hub or Ethernet HAT:

1. Connect Ethernet cable from your router/switch to the USB Ethernet adapter
2. Find the IP address:
   ```bash
   # From your router's admin page
   # Or scan your network:
   nmap -sn 192.168.1.0/24
   ```
3. SSH:
   ```bash
   ssh pi@192.168.1.xxx
   ```

---

## Quick Reference

| Method | Port to Use | Hostname | Speed |
|---|---|---|---|
| USB Ethernet | N/A | `raspberrypi.local` | Fast |
| Serial (TTL) | COMx or /dev/ttyUSB0 | N/A | Slow |
| Ethernet | N/A | IP address | Fastest |

---

## Troubleshooting

### Can't connect via USB Ethernet?

**Windows:**
1. Check Device Manager for "USB Ethernet/RNDIS Gadget"
2. If not showing, install driver manually

**All OS:**
1. Try pinging the hostname:
   ```bash
   ping raspberrypi.local
   ```
2. Check if Pi is getting power (LED should be on)

### SSH Connection Refused?

1. Make sure the `ssh` file exists in boot partition
2. Try:
   ```bash
   sudo systemctl enable ssh
   sudo systemctl start ssh
   ```

### Wrong Password?

The default password is `raspberry`. If changed and forgotten:
1. Re-flash SD card
2. Or edit `/etc/shadow` from Linux computer

---

## SSH Key Setup (Recommended)

To avoid typing password each time:

```bash
# On your computer, generate key:
ssh-keygen -t ed25519

# Copy to Pi:
ssh-copy-id pi@raspberrypi.local
```

---

## After Connecting - First Time Setup

```bash
# Update system
sudo apt update
sudo apt upgrade -y

# Set up WiFi (optional)
sudo raspi-config
# System Options → Wireless LAN

# Configure serial port for ESP32-C3
sudo raspi-config
# Interface Options → Serial Port
# Login shell: No
# Serial port: Yes

# Install dependencies
sudo apt install -y python3-pip
pip3 install flask flask-cors flask-socketio pyserial fpdf2 eventlet

# Copy station_monitor.py
mkdir -p ~/Stasis
# Copy base_station folder to ~/Stasis/
```

---

## Connect to Your STASIS Base Station

Once set up:

```bash
# SSH into Pi
ssh pi@stasis-base.local

# Check if station_monitor is running
sudo systemctl status stasis

# View logs
journalctl -u stasis -f

# Restart service
sudo systemctl restart stasis
```

Access the dashboard:
```
http://stasis-base.local:5000/stasis_app/index.html
```

---

*Document Version: 1.0*
*Last Updated: February 2026*

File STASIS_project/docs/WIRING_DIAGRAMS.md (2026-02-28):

# Complete Wiring Diagrams - Stasis Rover System

This document provides comprehensive wiring diagrams for all components of the Stasis system.

---

## Table of Contents

1. [System Overview](#1-system-overview)
2. [Rover Unit (ESP32-S3)](#2-rover-unit-esp32-s3)
3. [Vision Module (ESP32-CAM)](#3-vision-module-esp32-cam)
4. [Base Station (ESP32-C3 + RPi Zero)](#4-base-station-esp32-c3--rpi-zero)
5. [Power Distribution](#5-power-distribution)
6. [Complete Pin Reference](#6-complete-pin-reference)

---

## 1. System Overview

### Communication Flow

```
┌─────────────────────────────────────────────────────────────────────────────┐
│                           ROVER UNIT                                        │
│  ┌─────────────┐    ┌─────────────┐    ┌─────────────┐                   │
│  │ ESP32-S3    │◄──►│ ESP32-CAM   │    │   Motors    │                   │
│  │ (Main Ctrl) │    │  (Vision)   │    │  L9110S     │                   │
│  │             │    │             │    │             │                   │
│  │ UART1: Pi   │    │ Serial: S3  │    │ GPIO 4-7    │                   │
│  │ GPIO 43,44  │    │             │    │             │                   │
│  └──────┬──────┘    └──────┬──────┘    └─────────────┘                   │
│         │                  │                                                   │
│         │ ESP-NOW          │                                                   │
└─────────┼──────────────────┼───────────────────────────────────────────────────┘
          │                  │
          ▼                  ▼
┌─────────────────────────────────────────────────────────────────────────────┐
│                          BASE STATION                                       │
│  ┌─────────────┐    ┌─────────────┐    ┌─────────────┐                    │
│  │ ESP32-C3   │◄──►│ Raspberry   │    │   LCD       │                    │
│  │  (Bridge)  │    │   Pi Zero   │    │  16x2 I2C   │                    │
│  │             │    │             │    │             │                    │
│  │ UART: Pi   │    │ Flask API   │    │ I2C         │                    │
│  │ GPIO 20,21 │    │ Port 5000   │    │             │                    │
│  └─────────────┘    └──────┬──────┘    └─────────────┘                    │
└─────────────────────────────┼───────────────────────────────────────────────┘
                              │
                              │ HTTP
                              ▼
                    ┌─────────────────┐
                    │  Web Dashboard │
                    │ stasis_app/    │
                    └─────────────────┘
```

### Connection Summary

| Link | Protocol | Pins |
|---|---|---|
| Rover ↔ Camera | Serial (UART0) | RX/GPIO1, TX/GPIO3 |
| Rover ↔ Pi | UART1 | GPIO 43 (TX), GPIO 44 (RX) |
| Rover ↔ Base | ESP-NOW | Wireless |
| Base ↔ Pi | UART | GPIO 20 (TX), GPIO 21 (RX) |

---

## 2. Rover Unit (ESP32-S3)

### Complete Pin Map

```
┌─────────────────────────────────────────────────────────────────────────────┐
│                           ESP32-S3 DEVKIT                                  │
│                                                                             │
│  ┌─────┐                                                                     │
│  │ USB │                                                                     │
│  └──┬──┘                                                                     │
│     │                                                                        │
│  ┌──┴────────────────────────────────────────────────────────────────────┐  │
│  │                                                                       │  │
│  │  GPIO 1  ◄──── Battery Monitor (via voltage divider)                 │  │
│  │  GPIO 2  ◄──── MPU6050 SCL (I2C Clock)                               │  │
│  │  GPIO 3  ◄──── ESP32-CAM TX (Serial)                                │  │
│  │  GPIO 4  ────► L9110S B-IA (Left Motor PWM)                          │  │
│  │  GPIO 5  ────► L9110S B-IB (Left Motor Direction)                    │  │
│  │  GPIO 6  ────► L9110S A-IA (Right Motor PWM)                         │  │
│  │  GPIO 7  ────► L9110S A-IB (Right Motor Direction)                  │  │
│  │  GPIO 8  ◄──── GPS TX (SoftwareSerial RX)                            │  │
│  │  GPIO 9  ◄──── Ultrasonic Echo                                        │  │
│  │  GPIO 10 ────► Ultrasonic Trig                                        │  │
│  │  GPIO 12 ────► SIM800 RXD (optional)                                 │  │
│  │  GPIO 13 ◄──── SIM800 TXD (optional)                                 │  │
│  │  GPIO 21 ────► DS18B20 Data (with 4.7k pull-up)                     │  │
│  │  GPIO 42 ◄──── MPU6050 SDA (I2C Data)                               │  │
│  │  GPIO 43 ────► Pi RX (UART1 TX)                                      │  │
│  │  GPIO 44 ◄──── Pi TX (UART1 RX)                                      │  │
│  │  GPIO 45 ────► Status LED                                             │  │
│  │  GPIO 48 ────► Buzzer (+)                                             │  │
│  │                                                                       │  │
│  │  3.3V   ────► MPU6050 VCC, GPS VCC (if 3.3V compatible)            │  │
│  │  5V     ◄──── Buck Converter Output                                   │  │
│  │  GND    ────► Common Ground (ALL components)                         │  │
│  │                                                                       │  │
│  └───────────────────────────────────────────────────────────────────────┘  │
│                                                                             │
└─────────────────────────────────────────────────────────────────────────────┘
```

### UART Connections

```
ESP32-S3                        Raspberry Pi (via ESP32-C3)
┌─────────────┐                ┌─────────────┐
│             │                │             │
│ GPIO 43 (TX)│────────────────│ GPIO 20     │  ESP32-C3 RX
│             │                │             │
│ GPIO 44 (RX)│◄──────────────│ GPIO 21     │  ESP32-C3 TX
│             │                │             │
└─────────────┘                └─────────────┘

Note: Connection is through ESP32-C3 bridge, not direct to Pi
```
┌─────────────────────────────────────────────────────────────────────────────┐
│                           ESP32-S3 DEVKIT                                    │
│                                                                             │
│  ┌─────┐                                                                     │
│  │ USB │                                                                     │
│  └──┬──┘                                                                     │
│     │                                                                        │
│  ┌──┴────────────────────────────────────────────────────────────────────┐  │
│  │                                                                       │  │
│  │  GPIO 1  ◄──── Battery Monitor (via voltage divider)                 │  │
│  │  GPIO 2  ◄──── MPU6050 SCL (I2C Clock)                               │  │
│  │  GPIO 4  ────► L9110S B-IA (Left Motor PWM)                          │  │
│  │  GPIO 5  ────► L9110S B-IB (Left Motor Direction)                    │  │
│  │  GPIO 6  ────► L9110S A-IA (Right Motor PWM)                         │  │
│  │  GPIO 7  ────► L9110S A-IB (Right Motor Direction)                   │  │
│  │  GPIO 8  ◄──── GPS TX (SoftwareSerial RX)                            │  │
│  │  GPIO 12 ────► Ultrasonic Trig                                        │  │
│  │  GPIO 13 ◄──── Ultrasonic Echo (via voltage divider)                 │  │
│  │  GPIO 15 ────► SIM800 RXD                                             │  │
│  │  GPIO 16 ◄──── SIM800 TXD                                             │  │
│  │  GPIO 17 ◄──── ESP32-CAM TX (UART1 RX)                               │  │
│  │  GPIO 18 ────► ESP32-CAM RX (UART1 TX)                               │  │
│  │  GPIO 19 ────► GPS RX (SoftwareSerial TX)                            │  │
│  │  GPIO 21 ────► DS18B20 Data (with 4.7k pull-up)                      │  │
│  │  GPIO 42 ◄──── MPU6050 SDA (I2C Data)                                │  │
│  │  GPIO 45 ────► Status LED                                             │  │
│  │  GPIO 48 ────► Buzzer (+)                                             │  │
│  │                                                                       │  │
│  │  3.3V   ────► MPU6050 VCC, GPS VCC (if 3.3V compatible)              │  │
│  │  5V     ◄──── Buck Converter Output                                   │  │
│  │  GND    ────► Common Ground (ALL components)                          │  │
│  │                                                                       │  │
│  └───────────────────────────────────────────────────────────────────────┘  │
│                                                                             │
└─────────────────────────────────────────────────────────────────────────────┘
```

### Motor Driver (L9110S) Connections

```
                    L9110S Motor Driver
                   ┌─────────────────────┐
                   │                     │
    GPIO 4 ───────►│ B-IA   ││   A-IA ◄─────── GPIO 6
    GPIO 5 ───────►│ B-IB   ││   A-IB ◄─────── GPIO 7
                   │        ││                    │
    Left Motors ──►│ OUTB   ││   OUTA ◄─────────── Right Motors
                   │        ││                    │
    Buck 5V   ────►│ VCC    ││   GND ◄─────────── Common GND
                   │                     │
                   └─────────────────────┘

   LEFT SIDE (B Channel)          RIGHT SIDE (A Channel)
   ┌───────────────────┐          ┌───────────────────┐
   │   Front Left      │          │   Front Right     │
   │   Motor           │          │   Motor           │
   │   ───┬───         │          │   ───┬───         │
   │      │            │          │      │            │
   │   Rear Left       │          │   Rear Right      │
   │   Motor           │          │   Motor           │
   └───────────────────┘          └───────────────────┘
         ││                              ││
    Connect both to              Connect both to
    B screw terminals            A screw terminals
```

### Sensor Connections

#### MPU6050 (IMU)

```
    MPU6050                ESP32-S3
    ┌─────────┐           ┌─────────┐
    │  VCC    │──────────►│  3.3V   │
    │  GND    │──────────►│  GND    │
    │  SCL    │──────────►│ GPIO 2  │
    │  SDA    │──────────►│ GPIO 42 │
    │  XDA    │           │         │
    │  XCL    │           │         │
    │  AD0    │──────────►│  GND    │ (Address: 0x68)
    │  INT    │           │         │
    └─────────┘           └─────────┘
```

#### DS18B20 (Temperature)

```
                    4.7kΩ Resistor
    DS18B20            ┌───┐
    ┌─────────┐        │   │
    │  VCC    │────────┴───┴──────► 3.3V
    │  DATA   │────────────────────► GPIO 21
    │  GND    │────────────────────► GND
    └─────────┘
    
    Note: The 4.7kΩ pull-up resistor connects DATA to VCC
```

#### Ultrasonic Sensor (HC-SR04)

```
    HC-SR04              ESP32-S3
    ┌─────────┐         ┌─────────┐
    │  VCC    │────────►│  5V     │
    │  Trig   │────────►│ GPIO 12 │
    │  Echo   │──┬─────►│ GPIO 13 │
    │  GND    │  │      │         │
    └─────────┘  │      └─────────┘
                 │
            Voltage Divider (5V → 3.3V)
            ┌─────────────────────┐
            │                     │
            │   1kΩ      2kΩ     │
            │  ┌───┐    ┌───┐    │
    Echo ───┴──┤   ├──┬─┤   ├──┴──► GND
                  └───┘  │  └───┘
                         │
                         └──────────────► GPIO 13
```

#### GPS Module (Neo-6M)

```
    Neo-6M               ESP32-S3
    ┌─────────┐         ┌─────────┐
    │  VCC    │────────►│  3.3V   │
    │  GND    │────────►│  GND    │
    │  TX     │────────►│ GPIO 8  │ (SoftwareSerial RX)
    │  RX     │◄────────│ GPIO 19 │ (SoftwareSerial TX)
    └─────────┘         └─────────┘
```

#### SIM800L (GSM Module)

```
    SIM800L              ESP32-S3
    ┌─────────┐         ┌─────────┐
    │  VCC    │◄────────│ 4.0V Supply (NOT from ESP32!)
    │  GND    │────────►│  GND    │
    │  TXD    │────────►│ GPIO 16 │ (UART2 RX)
    │  RXD    │◄────────│ GPIO 15 │ (UART2 TX)
    │  RST    │         │         │
    └─────────┘         └─────────┘
    
    ⚠️ WARNING: SIM800L requires 3.4V-4.4V @ 2A peak!
    Use dedicated power supply or LiPo battery directly.
```

#### Battery Monitor

```
    LiPo Battery (12.6V max)
         │
         ├──────────────────────────────────────┐
         │                                      │
         │   Voltage Divider                    │
         │   ┌─────────────────┐                │
         │   │                 │                │
         │   │   30kΩ    10kΩ  │                │
         ├───┤  ┌───┐   ┌───┐  │                │
         │   │  │   │   │   │  │                │
         │   │  └───┴───┴───┴──┼────────────────┤
         │   │         │       │                │
         │   │         └───────┼────► GPIO 1    │
         │   │                 │    (ADC)       │
         │   └─────────────────┼────────────────┤
         │                     │                │
         └─────────────────────┴────► GND       │
                                                │
    Formula: ADC_Voltage = Battery_V × 10/(30+10)
             ADC_Voltage = Battery_V × 0.25
             Battery_V = ADC_Voltage × 4
```

---

## 3. Vision Module (ESP32-CAM)

### ESP32-CAM to ESP32-S3 Connection

The ESP32-CAM uses **Serial (UART0)** to communicate with the ESP32-S3 rover:

```
    ESP32-CAM                    ESP32-S3
    ┌─────────────┐             ┌─────────────┐
    │             │             │             │
    │  U0T (TX)   │────────────►│ GPIO 1 (RX) │  Serial
    │  U0R (RX)   │◄────────────│ GPIO 3 (TX) │  Serial
    │             │             │             │
    │  5V         │◄────────────│ 5V          │
    │  GND        │────────────►│ GND         │
    │             │             │             │
    └─────────────┘             └─────────────┘
    
    Note: Uses Serial (UART0), not UART1
```

### Communication Protocol

| From Rover | From Camera | Description |
|------------|-------------|-------------|
| Commands: 0x01-0x04 | `HAZARD:FIRE` | Fire detected |
| | `HAZARD:MOTION` | Motion detected |
| | `HAZARD:HUMAN` | Human detected |
| | `CAM:READY` | Camera initialized |
| | `CAM:ERROR` | Camera error |
| | `CLEAR` | No hazards |
    ESP32-CAM                    ESP32-S3
    ┌─────────────┐             ┌─────────────┐
    │             │             │             │
    │  U0T (TX)   │────────────►│ GPIO 17 (RX)│
    │  U0R (RX)   │◄────────────│ GPIO 18 (TX)│
    │             │             │             │
    │  5V         │◄────────────│ 5V          │
    │  GND        │────────────►│ GND         │
    │             │             │             │
    └─────────────┘             └─────────────┘
    
    Note: Both boards share the same 5V supply from Buck Converter
```

### ESP32-CAM Camera Connection

```
    ESP32-CAM Board
    ┌─────────────────────────────────┐
    │                                 │
    │   ┌─────────────────────────┐   │
    │   │   Camera Connector      │   │
    │   │   ┌─────────────────┐   │   │
    │   │   │ ▓▓▓▓▓▓▓▓▓▓▓▓▓▓▓ │   │   │
    │   │   │  Ribbon Cable   │   │   │
    │   │   │  (contacts down)│   │   │
    │   │   └─────────────────┘   │   │
    │   └─────────────────────────┘   │
    │                                 │
    │   OV2640 Camera Module          │
    │   ┌─────────────────────┐       │
    │   │  ┌───────────────┐  │       │
    │   │  │   Lens        │  │       │
    │   │  └───────────────┘  │       │
    │   └─────────────────────┘       │
    │                                 │
    └─────────────────────────────────┘
```

---

## 4. Base Station (ESP32-C3 + RPi Zero)

### ESP32-C3 to Raspberry Pi Zero

```
    ESP32-C3                    Raspberry Pi Zero
    ┌─────────────┐             ┌─────────────────────┐
    │             │             │                     │
    │  GPIO 21    │────────────►│ Pin 10 (GPIO 15 RX)│  UART TX → RPi RX
    │  (TX)       │             │                     │
    │             │             │                     │
    │  GPIO 20    │◄────────────│ Pin 8 (GPIO 14 TX) │  UART RX ← RPi TX
    │  (RX)       │             │                     │
    │             │             │                     │
    │  5V         │◄────────────│ Pin 2 (5V)         │  Power from RPi
    │             │             │                     │
    │  GND        │────────────►│ Pin 6 (GND)        │  Common Ground
    │             │             │                     │
    └─────────────┘             └─────────────────────┘
```

### Raspberry Pi Zero GPIO Header

```
    40-pin GPIO Header
    ┌────────────────────────────────────────┐
    │ 3.3V  [01] [02] 5V  ───► ESP32-C3    │  BOTTOM ROW (Even pins)
    │ SDA   [03] [04] 5V                    │  
    │ SCL   [05] [06] GND ───► ESP32-C3    │  
    │ GPIO4 [07] [08] TXD ───► ESP32-C3 RX  │  
    │ GND   [09] [10] RXD ◄─── ESP32-C3 TX  │  
    │ GPIO17[11] [12] GPIO18                │  TOP ROW - Available
    │ GPIO27[13] [14] GND                   │  for LCD, sensors
    │ GPIO22[15] [16] GPIO23                │  
    │ 3.3V  [17] [18] GPIO24                │  
    │ MOSI  [19] [20] GND                   │  
    │ MISO  [21] [22] GPIO25                │  
    │ SCLK  [23] [24] CE0                   │  
    │ GND   [25] [26] CE1                   │  
    └────────────────────────────────────────┘
```
    └────────────────────────────────────────┘
```

### LCD Display Connection (Controlled by ESP32-C3)

The LCD display is connected to the ESP32-C3, NOT the RPi Zero directly. The C3 receives display commands from RPi0W via UART and controls the LCD.

```
    LCD 16x2 I2C            ESP32-C3
    ┌─────────────┐         ┌─────────────────┐
    │  VCC        │────────►│ 5V (from RPi)   │
    │  GND        │────────►│ GND             │
    │  SDA        │────────►│ GPIO 4 (SDA)    │
    │  SCL        │────────►│ GPIO 5 (SCL)    │
    └─────────────┘         └─────────────────┘
    
    Note: LCD I2C Address typically 0x27 or 0x3F
```

### Complete Base Station Wiring Diagram

```
    ┌─────────────────────────────────────────────────────────────────────────┐
    │                         BASE STATION ARCHITECTURE                        │
    │                                                                          │
    │   ┌─────────────────┐         UART (Pins 8,10)        ┌───────────────┐ │
    │   │  USB Wall       │                                 │   ESP32-C3    │ │
    │   │  Charger (5V)   │    ┌───────────────────────┐    │               │ │
    │   └────────┬────────┘    │                       │    │  ┌─────────┐  │ │
    │            │             │   Raspberry Pi Zero   │    │  │ LCD     │  │ │
    │            ▼             │                       │    │  │ 16x2    │  │ │
    │   ┌─────────────────┐    │   ┌───────────────┐   │    │  │ I2C     │  │ │
    │   │  RPi Zero       │◄───┼───┤ UART RX (P10) │◄──┼────┤  │ Display │  │ │
    │   │  (Main Brain)   │    │   │ UART TX (P8)  │───┼───►│  └─────────┘  │ │
    │   │                 │    │   └───────────────┘   │    │               │ │
    │   │  - Processes    │    │                       │    │  GPIO 4 ─────┼─┼─► LCD SDA
    │   │    AprilTag     │    │   5V ─────────────────┼───►│  GPIO 5 ─────┼─┼─► LCD SCL
    │   │  - Generates    │    │   GND ────────────────┼───►│               │ │
    │   │    reports      │    │                       │    │  GPIO 21 ─────┼─┼─► RPi RX
    │   │  - Controls     │    └───────────────────────┘    │  GPIO 20 ─────┼─┼─► RPi TX
    │   │    display      │                                 │               │ │
    │   └─────────────────┘                                 │  ESP-NOW      │ │
    │                                                        │  (Wireless)   │ │
    │                                                        └───────┬───────┘ │
    │                                                                │         │
    │                                                                │         │
    │                                                        ESP-NOW │         │
    │                                                        (2.4GHz)│         │
    │                                                                ▼         │
    │                                                        ┌───────────────┐ │
    │                                                        │  Rover (S3)   │ │
    │                                                        │  + ESP32-CAM  │ │
    │                                                        └───────────────┘ │
    │                                                                          │
    └─────────────────────────────────────────────────────────────────────────┘
```

### Charging Docking Data Flow

```
    CHARGING STATION APPROACH SEQUENCE:
    
    1. ROVER APPROACH (GPS Navigation):
       ┌──────────┐    GPS Distance     ┌──────────┐
       │ Rover S3 │ ──────────────────► │ Base C3  │
       │          │    (ESP-NOW)        │          │
       └──────────┘                     └──────────┘
    
    2. APRILTAG DETECTION (Precise Alignment):
       ┌──────────┐   AprilTag Data    ┌──────────┐   AprilTag Data    ┌──────────┐
       │ ESP32-CAM│ ──────────────────►│ Rover S3 │ ──────────────────►│ Base C3  │
       │ (on S3)  │    (UART)          │          │    (ESP-NOW)       │          │
       └──────────┘                    └──────────┘                    └──────────┘
                                                                            │
                                                                            ▼
       ┌──────────┐  Alignment Cmds    ┌──────────┐  Processed Data    ┌──────────┐
       │ Rover S3 │ ◄───────────────── │ Base C3  │ ◄───────────────── │ RPi Zero │
       │          │    (ESP-NOW)       │          │    (UART)          │          │
       └──────────┘                    └──────────┘                    └──────────┘
    
    3. DOCKING & CHARGING:
       ┌──────────┐   Charging Status  ┌──────────┐   Display Cmds     ┌──────────┐
       │ Rover S3 │ ──────────────────►│ Base C3  │ ◄───────────────── │ RPi Zero │
       │          │    (ESP-NOW)       │          │    (UART)          │          │
       └──────────┘                    └──────────┘                    └──────────┘
                                             │
                                             ▼
                                       ┌──────────┐
                                       │ LCD 16x2 │
                                       │ Display  │
                                       └──────────┘
    
    4. REPORT GENERATION:
       ┌──────────┐   All Log Data     ┌──────────┐   Raw Data         ┌──────────┐
       │ Rover S3 │ ──────────────────►│ Base C3  │ ──────────────────►│ RPi Zero │
       │          │    (ESP-NOW)       │          │    (UART)          │          │
       └──────────┘                    └──────────┘                    └──────────┘
                                                                             │
                                                                             ▼
                                                                       ┌──────────┐
                                                                       │ Daily    │
                                                                       │ Report   │
                                                                       │ (PDF)    │
                                                                       └──────────┘
```

### ESP32-C3 Pin Map (Complete)

```
    ESP32-C3 DEVKIT
    ┌─────────────────────────────────────────────────────────────────────────┐
    │                                                                         │
    │  GPIO 4  ◄────► LCD SDA (I2C Data)                                     │
    │  GPIO 5  ◄────► LCD SCL (I2C Clock)                                    │
    │  GPIO 8  ────► Built-in LED (Status)                                   │
    │  GPIO 20 ◄────► RPi Zero TXD (Pin 8) - UART RX                         │
    │  GPIO 21 ────► RPi Zero RXD (Pin 10) - UART TX                         │
    │                                                                         │
    │  5V     ◄──── RPi Zero 5V (Pin 2)                                      │
    │  GND    ────► Common Ground                                            │
    │                                                                         │
    │  ESP-NOW Antenna (Built-in) ──── Wireless to Rover S3                  │
    │                                                                         │
    └─────────────────────────────────────────────────────────────────────────┘
```

---

## 4. Power Distribution

### Rover Power System

```
    LiPo Battery (3S, 11.1V - 12.6V)
    ┌─────────────────────────────────────────────────────────────┐
    │                                                             │
    │   ┌─────────────────────────────────────────────────────┐   │
    │   │                 Buck Converter                       │   │
    │   │               (12V → 5V, 5A max)                     │   │
    │   │                                                      │   │
    │──►│  IN+     IN-     OUT+    OUT-                       │   │
    │   │  │       │       │       │                          │   │
    │   └──┼───────┼───────┼───────┼──────────────────────────┘   │
    │      │       │       │       │                              │
    │      │       │       │       │                              │
    │      │       │       │       └──────────────────► GND       │
    │      │       │       │                                      │
    │      │       │       └───────────────────────► 5V Rail      │
    │      │       │                                              │
    │      │       └──────────────────────────────────► GND       │
    │      │                                                      │
    │      └──────────────────────────────────────────────► Battery+
    │                                                             │
    └─────────────────────────────────────────────────────────────┘
    
    5V Rail Distribution:
    ┌─────────────────────────────────────────────────────────────┐
    │  5V ───┬───► ESP32-S3 (5V pin)                             │
    │        ├───► ESP32-CAM (5V pin)                             │
    │        ├───► L9110S Motor Driver (VCC)                      │
    │        ├───► Ultrasonic Sensor (VCC)                        │
    │        └───► SIM800L (via dedicated regulator)              │
    │                                                             │
    │  3.3V (from ESP32-S3) ───┬───► MPU6050                      │
    │                          ├───► DS18B20                      │
    │                          └───► GPS (if 3.3V compatible)     │
    └─────────────────────────────────────────────────────────────┘
```

### Base Station Power System

```
    USB Wall Charger (5V, 2.5A)
    ┌─────────────────────────────────────────────────────────────┐
    │                                                             │
    │   ┌─────────────────────────────────────────────────────┐   │
    │   │              Raspberry Pi Zero                        │   │
    │   │                                                      │   │
    │──►│  micro-USB PWR                                       │   │
    │   │                                                      │   │
    │   │  5V Pin (Pin 2) ─────────────► ESP32-C3 (5V)         │   │
    │   │  GND Pin (Pin 6) ◄──────────── ESP32-C3 (GND)        │   │
    │   │                                                      │   │
    │   │  5V Pin (Pin 2) ─────────────► LCD VCC               │   │
    │   │  GND Pin (Pin 6) ◄──────────── LCD GND               │   │
    │   │                                                      │   │
    │   └──────────────────────────────────────────────────────┘   │
    │                                                             │
    └─────────────────────────────────────────────────────────────┘
    
    Power Distribution from RPi Zero:
    ┌─────────────────────────────────────────────────────────────┐
    │  5V (Pin 2) ───┬───► ESP32-C3 (5V pin)                     │
    │                └───► LCD Display (VCC)                      │
    │                                                             │
    │  GND (Pin 6) ──┬───► ESP32-C3 (GND)                         │
    │                └───► LCD Display (GND)                      │
    └─────────────────────────────────────────────────────────────┘
```

---

## 5. Important Safety Notes

### Voltage Level Warnings

| Component | Logic Level | Warning |
|-----------|-------------|---------|
| ESP32-S3 | 3.3V | **Do NOT connect 5V signals directly!** |
| ESP32-C3 | 3.3V | **Do NOT connect 5V signals directly!** |
| ESP32-CAM | 3.3V | **Do NOT connect 5V signals directly!** |
| Ultrasonic Echo | 5V output | **Requires voltage divider!** |
| SIM800L | 3.4V-4.4V | **Do NOT power from ESP32!** |

### Required Voltage Dividers

```
    5V Signal to 3.3V GPIO:
    
    5V Signal ───┬────────────────────► 3.3V GPIO
                 │
               ┌─┴─┐
               │   │ 1kΩ
               └─┬─┘
                 │
                 ├────────────────────► GND
               ┌─┴─┐
               │   │ 2kΩ
               └─┬─┘
                 │
                GND
    
    Output: 5V × (2kΩ / (1kΩ + 2kΩ)) = 3.33V ✓
```

### Current Requirements

| Component | Typical Current | Peak Current |
|-----------|-----------------|--------------|
| ESP32-S3 | 150mA | 500mA |
| ESP32-CAM | 80mA | 300mA (flash LED) |
| ESP32-C3 | 100mA | 400mA |
| LCD 16x2 | 20mA | 50mA (with backlight) |
| SIM800L | 10mA (idle) | 2A (transmit) |
| Motors (4x) | 500mA | 2A (stall each) |
| GPS | 25mA | 50mA |
| MPU6050 | 3mA | 10mA |
| DS18B20 | 1mA | 5mA |
| Ultrasonic | 2mA | 15mA |

**Total Rover Peak: ~6A** (ensure buck converter can handle this)
**Total Base Station Peak: ~1A** (USB charger should be 2.5A minimum)

### Ground Rules

1. **Common Ground**: ALL components must share a common ground
2. **Star Ground**: Connect all grounds to a single point when possible
3. **No Ground Loops**: Avoid creating ground loops in wiring

---

## 6. Complete Pin Reference

### Rover (ESP32-S3) Pin Summary

| GPIO | Function | Connection | Notes |
|------|----------|------------|-------|
| 1 | Serial RX | ESP32-CAM TX | UART0 |
| 2 | I2C SCL | MPU6050 | |
| 3 | Serial TX | ESP32-CAM RX | UART0 |
| 4 | PWM | Motor Left Speed | L9110S B-IA |
| 5 | Digital | Motor Left Direction | L9110S B-IB |
| 6 | PWM | Motor Right Speed | L9110S A-IA |
| 7 | Digital | Motor Right Direction | L9110S A-IB |
| 8 | Serial RX | GPS TX | |
| 9 | Digital | Ultrasonic Echo | |
| 10 | Digital | Ultrasonic Trig | |
| 12 | Digital | SIM800 RX (optional) | |
| 13 | Digital | SIM800 TX (optional) | |
| 21 | OneWire | DS18B20 | 4.7k pull-up |
| 42 | I2C SDA | MPU6050 | |
| 43 | Serial TX | ESP32-C3 RX | UART1 |
| 44 | Serial RX | ESP32-C3 TX | UART1 |
| 45 | Digital | Status LED | |
| 48 | Digital | Buzzer | |

### Camera (ESP32-CAM) Pin Summary

| Pin | Function | Connection |
|-----|----------|------------|
| U0T | Serial TX | ESP32-S3 GPIO 1 |
| U0R | Serial RX | ESP32-S3 GPIO 3 |
| 5V | Power | Buck Converter 5V |
| GND | Ground | Common GND |

### Base Station Pin Summary

| ESP32-C3 GPIO | Function | Connection |
|---------------|----------|------------|
| 8 | LED | Built-in Status |
| 20 | UART RX | RPi Zero TXD (Pin 8) |
| 21 | UART TX | RPi Zero RXD (Pin 10) |

| RPi Zero Pin | Function | Connection |
|--------------|----------|------------|
| 2 | 5V Power | ESP32-C3 5V |
| 6 | GND | ESP32-C3 GND |
| 8 | TXD (GPIO 14) | ESP32-C3 RX (GPIO 20) |
| 10 | RXD (GPIO 15) | ESP32-C3 TX (GPIO 21) |

---

### Complete Data Flow

```
┌──────────────┐     Serial      ┌──────────────┐    UART1    ┌──────────────┐
│ ESP32-CAM   │◄──────────────►│  ESP32-S3   │◄───────────►│  ESP32-C3   │
│             │   (UART0)       │   (Rover)   │  (GPIO 43/44)│  (Bridge)   │
└──────────────┘                 └──────────────┘              └──────┬───────┘
      │                                                               │
      │ HAZARD: messages                                              │ UART
      │ forwarded                                                     │ (GPIO 20/21)
      │                                                               ▼
      │                                              ┌───────────────────────┐
      │                                              │    Raspberry Pi Zero  │
      │                                              │                       │
      │                                              │  station_monitor.py  │
      │                                              │  - Parse telemetry   │
      │                                              │  - Store SQLite DB  │
      │                                              │  - Serve API         │
      │                                              │                       │
      │                                              │  /api/status         │
      │                                              │  /api/command        │
      │                                              │  /api/alerts         │
      │                                              └───────────────────────┘
      │                                                        │
      │                                                        │ HTTP
      ▼                                                        ▼
┌─────────────────────────────────────────────────────────────────────┐
│                        Web Dashboard (stasis_app/index.html)        │
│                                                                     │
│  Dashboard │ Map │ Stream │ Chat │ Fencing                         │
└─────────────────────────────────────────────────────────────────────┘
```

---

*Document Version: 3.0*  
*Last Updated: February 2026*

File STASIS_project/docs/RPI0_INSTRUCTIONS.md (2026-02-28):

# Raspberry Pi Zero - Base Station Setup Instructions

## Overview

This guide sets up the Raspberry Pi Zero to:
- Automatically run the station monitor Python script on power-up
- Connect to the ESP32-C3 via UART for rover communication
- Serve the web dashboard and REST API
- Operate in headless mode (no monitor/keyboard required)

---

## Hardware Requirements

### Components
- Raspberry Pi Zero (any version: Pi Zero, Pi Zero W, or Pi Zero 2 W)
- MicroSD Card (8GB minimum, 16GB recommended)
- 5V Power Supply (2.5A recommended)
- ESP32-C3 (connected via UART)

### Optional
- USB to TTL adapter (for initial headless setup)
- HDMI adapter and monitor (for debugging)

---

## Operating System Setup

### Step 1: Download Raspberry Pi OS

Download **Raspberry Pi OS Lite** (no desktop environment needed):
- URL: https://www.raspberrypi.com/software/operating-systems/
- Choose: **Raspberry Pi OS Lite (64-bit or 32-bit)**

### Step 2: Flash the SD Card

Use **Raspberry Pi Imager**:

1. Download from: https://www.raspberrypi.com/software/
2. Insert SD card into computer
3. Open Raspberry Pi Imager
4. Select OS: **Raspberry Pi OS (other)** → **Raspberry Pi OS Lite**
5. Select your SD card
6. Click the **gear icon** (Advanced options):
   - Set hostname: `stasis-base`
   - Enable SSH: **Yes**
   - Set username/password: `pi` / `sentinel2024`
   - Configure wireless LAN: (optional, for internet access)
   - Set locale settings: Your timezone
7. Click **Save** then **Write**

### Step 3: Enable Serial Port

```bash
sudo raspi-config
```

Navigate to:
1. **Interface Options** → **Serial Port**
2. Login shell on serial: **No**
3. Serial port hardware enabled: **Yes**
4. Reboot when prompted

---

## Install Required Packages

### Step 1: Install Python Dependencies

```bash
sudo apt install -y python3-pip python3-venv
sudo pip3 install flask flask-cors flask-socketio pyserial fpdf2 eventlet
```

### Step 2: Copy Station Monitor Script

```bash
mkdir -p ~/Stasis
cd ~/Stasis
scp -r base_station pi@stasis-base.local:~/Stasis/
```

---

## Auto-Start Configuration

### systemd Service (Recommended)

Create a systemd service:

```bash
sudo nano /etc/systemd/system/stasis.service
```

Add:

```ini
[Unit]
Description=Stasis Base Station Monitor
After=network.target serial-getty@serial0.service

[Service]
Type=simple
User=pi
WorkingDirectory=/home/pi/Stasis
ExecStart=/usr/bin/python3 /home/pi/Stasis/base_station/station_monitor.py
Restart=always
RestartSec=10
StandardOutput=journal
StandardError=journal

Environment="SERIAL_PORT=/dev/serial0"
Environment="BAUD_RATE=115200"
Environment="FLASK_HOST=0.0.0.0"
Environment="FLASK_PORT=5000"

[Install]
WantedBy=multi-user.target
```

Enable:

```bash
sudo systemctl daemon-reload
sudo systemctl enable stasis.service
sudo systemctl start stasis.service
```

---

## Wiring: ESP32-C3 to Raspberry Pi Zero

| ESP32-C3 | Raspberry Pi Zero | Function |
|---|---|---|
| GPIO 21 (TX) | Pin 10 (GPIO 15 RXD) | UART TX → RX |
| GPIO 20 (RX) | Pin 8 (GPIO 14 TXD) | UART RX ← TX |
| 5V | Pin 2 or 4 (5V) | Power |
| GND | Pin 6 (GND) | Common Ground |

---

## Testing the Setup

### Test 1: Check Serial Communication

```bash
sudo apt install minicom
minicom -D /dev/serial0 -b 115200
```

You should see telemetry JSON from ESP32-C3. Press Ctrl+A then X to exit.

### Test 2: Check Flask API

```bash
# Public endpoint (no auth required)
curl http://stasis-base.local:5000/api/health

# Authenticated endpoints (default key: stasis-2024)
curl -H "X-API-Key: stasis-2024" http://stasis-base.local:5000/api/status
```

### Test 3: Access Web Dashboard

Open browser:
```
http://stasis-base.local:5000/stasis_app/index.html
```

---

## API Usage

### Send Command to Rover

```bash
curl -X POST http://stasis-base.local:5000/api/command \
  -H "Content-Type: application/json" \
  -H "X-API-Key: stasis-2024" \
  -d '{"cmd":"PATROL"}'
```

Available commands: STOP, FORWARD, BACKWARD, LEFT, RIGHT, PATROL, HOME, DOCKING, RESEARCH, RESET

### Get Telemetry

```bash
curl http://stasis-base.local:5000/api/status \
  -H "X-API-Key: stasis-2024"
```

### Get Alerts

```bash
curl http://stasis-base.local:5000/api/alerts \
  -H "X-API-Key: stasis-2024"
```

---

## Troubleshooting

### Serial Port Not Found

```bash
ls -la /dev/serial0
# Should show: /dev/serial0 -> ttyAMA0
```

### Service Not Starting

```bash
journalctl -u stasis.service -n 50
python3 -m py_compile ~/Stasis/base_station/station_monitor.py
```

### Permission Denied

```bash
sudo usermod -a -G dialout pi
# Logout and login again
```

---

## Power-On Behavior

1. **Boot** (30-60 seconds) - Raspberry Pi OS loads
2. **Service Start** - stasis.service starts automatically
3. **Normal Operation**:
   - Listens for telemetry from ESP32-C3
   - Serves REST API on port 5000
   - Stores data in SQLite database
   - Generates PDF/TXT reports when rover docks
   - WebSocket for real-time updates

---

## Next Steps

After setting up the Raspberry Pi Zero:
1. Verify ESP32-C3 connection with `minicom`
2. Flash the [ESP32-C3 bridge](./ESP32-C3_INSTRUCTIONS.md)
3. Flash the [ESP32-S3 rover](./ESP32-S3_INSTRUCTIONS.md)
4. Test end-to-end communication

---

*Document Version: 2.0*  
*Last Updated: February 2026*

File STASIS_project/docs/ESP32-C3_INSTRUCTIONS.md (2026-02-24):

# ESP32-C3 Base Station Bridge - Flashing Instructions

## Overview

The ESP32-C3 serves as a **GPIO Extender and Display Controller** for the Raspberry Pi Zero W, while also functioning as a communication bridge. It handles:
- ESP-NOW wireless communication with the ESP32-S3 rover
- UART serial communication with the Raspberry Pi Zero
- **LCD 16x2 I2C display control** (shows rover status, location, docking progress)
- **AprilTag data routing** (from ESP32-CAM → S3 → C3 → RPi for processing)
- Message queuing and reliability
- WiFi Access Point for status indication
- LED status indicators
- Multi-rover support (up to 4 rovers)
- Heartbeat signal for connection monitoring
- Web server for real-time status display

### Key Architecture Change
The C3 now connects **only to the bottom row of the RPi0W GPIO header** (the row starting with the double 5V pins - pins 2, 4, 6, 8, 10...). This allows the RPi0W to maintain full control while the C3 acts as a GPIO extender for:
- LCD display output
- UART communication bridge
- AprilTag data routing

---

## Hardware Requirements

### Components
- ESP32-C3 Development Board (ESP32-C3-DEVKITC-02 or similar)
- USB-C or USB-Micro cable for programming
- Computer with Arduino IDE installed
- **LCD 16x2 I2C Display** (optional, for status display)

### Board Specifications
- Flash Memory: 4MB (typical)
- USB: Some boards have native USB, others use USB-Serial bridge

---

## Software Setup - Arduino IDE

### Step 1: Install Arduino IDE

Download and install Arduino IDE from:
- https://www.arduino.cc/en/software

### Step 2: Add ESP32 Board Support

1. Open Arduino IDE
2. Go to **File** → **Preferences**
3. In "Additional Boards Manager URLs", add:
   ```
   https://raw.githubusercontent.com/espressif/arduino-esp32/gh-pages/package_esp32_index.json
   ```
4. Go to **Tools** → **Board** → **Boards Manager**
5. Search for "esp32" and install **esp32 by Espressif Systems**

### Step 3: Select ESP32-C3 Board

1. Go to **Tools** → **Board** → **esp32**
2. Select **ESP32C3 Dev Module**

### Step 4: Configure Board Settings

| Setting | Value |
|---|---|
| Board | ESP32C3 Dev Module |
| Upload Speed | 921600 |
| USB CDC On Boot | Enabled |
| Partition Scheme | Default 4MB with spiffs |
| CPU Frequency | 160MHz |
| Flash Mode | QIO |
| Flash Size | 4MB |
| Flash Frequency | 80MHz |
| Core Debug Level | None |

---

## Required Libraries

### Install via Library Manager

| Library | Version | Purpose |
|---|---|---|
| ArduinoJson | 6.x or 7.x | JSON serialization |

### Built-in Libraries (No installation needed)
- WiFi
- ESP-NOW
- WebServer
- Wire (I2C)

---

## Firmware Upload

### Step 1: Connect ESP32-C3

1. Connect ESP32-C3 to computer via USB
2. Wait for drivers to install

### Step 2: Select Port

1. Go to **Tools** → **Port**
2. Select the appropriate COM port

### Step 3: Upload

1. Open `base_bridge/base_bridge.ino`
2. Click **Verify** to compile
3. Click **Upload**
4. Wait for "Done uploading"

### Boot Mode for ESP32-C3

If upload fails, try:
1. Hold **BOOT** button
2. Click **Upload** in Arduino IDE
3. Release **BOOT** when "Connecting..." appears
4. Press **RST** (Reset) button after upload completes

---

## Configuration Before Upload

### Required Changes in Code

Open `base_bridge.ino` and modify:

```cpp
// Set your rover's MAC address
uint8_t roverMac[] = {0xFF, 0xFF, 0xFF, 0xFF, 0xFF, 0xFF};
// Replace with actual ESP32-S3 MAC address
```

### Finding ESP32-S3 MAC Address

To find the MAC address of your ESP32-S3 (rover):

1. Flash the ESP32-S3 with rover_main.ino
2. Open Serial Monitor at 115200 baud
3. The MAC address will be printed on startup
4. Update the `roverMac[]` array in base_bridge.ino

### Multi-Rover Configuration

The firmware supports up to 5 rovers. Add additional MAC addresses:

```cpp
// Add multiple rovers
uint8_t roverMacs[][6] = {
  {0xAA, 0xBB, 0xCC, 0xDD, 0xEE, 0xF1},  // Rover 1
  {0xAA, 0xBB, 0xCC, 0xDD, 0xEE, 0xF2},  // Rover 2
  {0xAA, 0xBB, 0xCC, 0xDD, 0xEE, 0xF3},  // Rover 3
};
int roverCount = 3;
```

---

## WiFi Access Point Feature

The ESP32-C3 creates a WiFi Access Point for status indication:

| Setting | Value |
|---|---|
| SSID | `Stasis-Base` |
| Password | `stasis123` |
| IP Address | 192.168.4.1 |
| Port | 80 |

### Status Page

Connect to the AP and open `http://192.168.4.1` in a browser to see:
- Connection status
- Packets received count
- Commands sent count
- ESP-NOW status
- Rover registry
- System diagnostics

### Web API Endpoints

| Endpoint | Method | Description |
|---|---|---|
| `/` | GET | Status page (HTML) |
| `/api/status` | GET | JSON status |
| `/api/rover` | GET | List registered rovers |
| `/api/command` | POST | Send command to rover |
| `/api/config` | GET/POST | Get/set configuration |
| `/api/diagnostics` | GET | System diagnostics |

---

## Pin Connections

### ESP32-C3 to Raspberry Pi Zero (Bottom Row Only)

The C3 connects **only to the bottom row** of the RPi0W GPIO header (the row starting with double 5V - pins 2, 4, 6, 8, 10...):

```
RPi0W GPIO Header (Bottom Row - Outer Edge):
┌─────────────────────────────────────────┐
│ Pin 2  │ Pin 4  │ Pin 6  │ Pin 8  │ Pin 10 │ ...
│  5V    │  5V    │  GND   │ TXD    │  RXD   │
│   │    │   │    │   │    │   │    │   │    │
│   └────┴───┴────┴───┴────┴───┴────┴───┘    │
│              │       │       │            │
│           GND      GPIO20  GPIO21         │
│           (C3)     (C3)    (C3)           │
└─────────────────────────────────────────┘
```

| ESP32-C3 Pin | RPi Zero Pin | Function |
|---|---|---|
| GPIO 21 (TX) | Pin 10 (RXD) | UART TX to Pi |
| GPIO 20 (RX) | Pin 8 (TXD) | UART RX from Pi |
| 5V | Pin 2 (5V) | Power from Pi |
| GND | Pin 6 (GND) | Common Ground |

### ESP32-C3 to Status LED

| ESP32-C3 Pin | LED | Function |
|---|-----|---|
| GPIO 8 | LED Anode | Status indicator (built-in on most boards) |
| GND | LED Cathode | Via 220Ω resistor (if external) |

---

## Data Structures

### RoverPacket (Telemetry from Rover)

```cpp
typedef struct __attribute__((packed)) {
  int     id;           // Packet ID
  float   temp;         // Temperature (°C)
  float   bat;          // Battery percentage
  double  lat;          // GPS latitude
  double  lng;          // GPS longitude
  bool    hazard;       // Hazard detected
  char    status[32];   // Rover status string
  float   distance;     // Ultrasonic distance
  float   accelX;       // Accelerometer X
  float   accelY;       // Accelerometer Y
  float   heading;      // Compass heading
  bool    streaming;    // Video streaming active
} RoverPacket;
```

### CommandPacket (Commands to Rover)

```cpp
typedef struct __attribute__((packed)) {
  char cmd[16];   // Command string
} CommandPacket;
```

---

## Communication Protocol

### ESP-NOW (Rover ↔ Bridge)

The bridge receives telemetry from the rover via ESP-NOW at 115200 baud.

### UART (Bridge ↔ Pi)

Data is forwarded to the Pi via UART at 115200 baud.

**Telemetry Format (JSON):**
```json
{
  "id": 123,
  "temp": 25.5,
  "bat": 85.0,
  "lat": 12.3456,
  "lng": 78.9012,
  "hazard": false,
  "status": "PATROL",
  "distance": 150.5,
  "accelX": 0.1,
  "accelY": 0.05,
  "heading": 45.2,
  "streaming": false
}
```

**Command Format:**
Commands from Pi to rover are sent as plain text:
- `START` - Start patrol
- `STOP` - Stop movement
- `RETURN` - Return to base
- `DOCK` - Initiate docking
- `CALIBRATE` - Calibrate sensors
- `STATUS` - Request status
- `FORWARD` - Move forward
- `BACKWARD` - Move backward
- `LEFT` - Turn left
- `RIGHT` - Turn right

---

## Message Queue System

The firmware implements a reliable message queue:

| Parameter | Value | Description |
|---|---|---|
| `QUEUE_SIZE` | 10 | Maximum queued commands |
| `MAX_RETRIES` | 3 | Retry attempts per command |
| `RETRY_DELAY_MS` | 100 | Delay between retries |
| `HEARTBEAT_MS` | 5000 | Heartbeat interval |
| `RECONNECT_MS` | 30000 | Reconnection attempt interval |

---

## LED Status Indicators

| Pattern | Meaning |
|---|---|
| 1 blink | Data received from rover |
| 2 blinks | Command sent successfully |
| 3 blinks | Error in communication |
| 5 blinks | ESP-NOW reconnected |
| Long blink (500ms) | ESP-NOW ready |
| Rapid blink | Error state |

---

## Testing After Upload

### Serial Monitor Test

1. Open Serial Monitor at **115200** baud
2. You should see:
   ```
   ========================
   Stasis Base Station Bridge
   ========================
   MAC: XX:XX:XX:XX:XX:XX
   SSID: Stasis-Base
   IP: 192.168.4.1
   Status page: http://192.168.4.1
   ========================
   Bridge ready
   ```

### WiFi AP Test

1. On your phone/laptop, scan for WiFi networks
2. Connect to `Stasis-Base` (password: `stasis123`)
3. Open browser and go to `http://192.168.4.1`
4. You should see the status page with ESP-NOW status

### UART Test with Pi

1. Connect ESP32-C3 to Raspberry Pi Zero
2. On the Pi, run: `python3 -c "import serial; s=serial.Serial('/dev/serial0', 115200); print(s.readline())"`
3. You should see heartbeat messages every 5 seconds

### API Test

Test the REST API with curl:

```bash
# Get status
curl http://192.168.4.1/api/status

# Send command
curl -X POST -d "cmd=START" http://192.168.4.1/api/command

# Get diagnostics
curl http://192.168.4.1/api/diagnostics
```

---

## Troubleshooting

### ESP-NOW Not Initializing
- Check WiFi is in AP mode before ESP-NOW init
- Try resetting the board
- Check for interference from other 2.4GHz devices
- Ensure correct MAC address format

### UART Communication Issues
- Verify TX/RX are not swapped (GPIO 21 = TX, GPIO 20 = RX)
- Check baud rate matches (115200)
- Ensure common ground connection
- Check serial cable quality

### WiFi AP Not Visible
- Wait 30 seconds after boot for AP to start
- Check if ESP-NOW is using the same channel
- Try restarting the ESP32-C3
- Verify WiFi antenna (if external)

### Upload Fails
- Hold BOOT button during upload start
- Check USB cable is data-capable (not charge-only)
- Try different USB port
- Install CP210x or CH340 drivers if needed

### Commands Not Reaching Rover
- Verify rover MAC address is correct
- Check ESP-NOW peer is registered
- Ensure rover is powered on and in range
- Check for RF interference

---

## Advanced Features

### Diagnostic Logging

View diagnostic logs via serial:

```
DIAG: Uptime=3600s
DIAG: Heap=45000 bytes
DIAG: Packets=1234
DIAG: Errors=5
DIAG: Rovers=2
```

### Configuration Storage

Settings are stored in EEPROM and persist across reboots:
- Rover MAC addresses
- WiFi credentials
- UART baud rate
- LED patterns

---

## Next Steps

After flashing the ESP32-C3:
1. Connect to Raspberry Pi Zero via UART (bottom row pins only)
2. Set up the [Raspberry Pi Zero software](./RPI0_INSTRUCTIONS.md)
3. Flash the [ESP32-S3 rover](./ESP32-S3_INSTRUCTIONS.md) with the correct MAC address
4. Configure [ESP32-CAM for AprilTag detection](./ESP32-CAM_INSTRUCTIONS.md)
5. Test end-to-end communication
6. Review the complete [wiring diagram](./WIRING_DIAGRAMS.md)
7. Check the [AprilTag docking guide](./APRILTAG_DOCKING_GUIDE.md) for autonomous docking

---

*Document Version: 2.1*  
*Last Updated: February 2026*

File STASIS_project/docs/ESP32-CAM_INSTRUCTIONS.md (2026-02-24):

# ESP32-CAM Vision Module - Flashing Instructions

## Overview

The ESP32-CAM handles all vision-related tasks for the rover:
- Image capture and processing
- Fire detection (color + brightness analysis)
- Motion detection (frame differencing)
- Human detection (skin-tone pattern analysis)
- Frame streaming on demand

---

## Hardware Requirements

### Components
- ESP32-CAM Module (AI Thinker version recommended)
- FTDI Programmer / USB-TTL Serial Adapter (3.3V compatible)
- Jumper wires
- 5V power supply (for testing)

### ESP32-CAM Specifications
- Flash Memory: 4MB
- PSRAM: 4MB (external)
- Camera: OV2640 (2MP)
- USB: **No native USB** - requires external programmer

---

## Flashing Methods

### Method 1: Arduino IDE (Recommended)

#### Step 1: Install Arduino IDE

Download from: https://www.arduino.cc/en/software

#### Step 2: Add ESP32 Board Support

1. Go to **File** → **Preferences**
2. Add to "Additional Boards Manager URLs":
   ```
   https://raw.githubusercontent.com/espressif/arduino-esp32/gh-pages/package_esp32_index.json
   ```
3. Go to **Tools** → **Board** → **Boards Manager**
4. Install **esp32 by Espressif Systems**

#### Step 3: Select ESP32-CAM Board

1. Go to **Tools** → **Board** → **esp32**
2. Select **AI Thinker ESP32-CAM**

#### Step 4: Configure Board Settings

| Setting | Value |
|---|---|
| Board | AI Thinker ESP32-CAM |
| Upload Speed | 115200 |
| CPU Frequency | 240MHz (WiFi/BT) |
| Flash Mode | QIO |
| Flash Size | 4MB |
| Partition Scheme | Huge App (3MB No OTA) |
| Core Debug Level | None |

---

## Wiring for Flashing

### FTDI/USB-TTL Connection

The ESP32-CAM does not have a USB port. You must use an FTDI programmer:

```
ESP32-CAM          FTDI Programmer
----------         ---------------
  U0R (RX)  <------  TX
  U0T (TX)  ------>  RX
  GND       -------  GND
  5V        <------- 5V (or 3.3V)
  
  IO0       -------  GND (for flash mode only!)
```

### Important Flash Mode Setup

**To enter flash mode:**
1. Connect **IO0 to GND** (this puts ESP32-CAM in download mode)
2. Power on the ESP32-CAM
3. Upload the code
4. Disconnect **IO0 from GND**
5. Press the **RST** (reset) button or repower

### Wiring Diagram

```
                    ┌─────────────────┐
                    │   FTDI/TTL      │
                    │   Programmer    │
                    │                 │
                    │  5V  ───────────┼─────┐
                    │  GND ───────────┼──┐  │
                    │  TX  ───────────┼──┼──┼──┐
                    │  RX  ───────────┼──┼──┼──┼──┐
                    └─────────────────┘  │  │  │  │
                                         │  │  │  │
                    ┌─────────────────┐  │  │  │  │
                    │   ESP32-CAM     │  │  │  │  │
                    │                 │  │  │  │  │
           5V  <────┼─ 5V             │  │  │  │  │
          GND  <────┼─ GND            │  │  │  │  │
          RX   <────┼─ U0R            │◄─┘  │  │  │
          TX   ─────┼─ U0T            │────►│  │  │
                    │                 │     │  │  │
                    │  IO0 ───────────┼─────┼──┼──┼── GND (flash mode)
                    │                 │     │  │  │
                    └─────────────────┘     │  │  │
                                            │  │  │
                    (Disconnect IO0 from    │  │  │
                     GND after flashing)    │  │  │
```

---

## Firmware Upload

### Step 1: Wire the ESP32-CAM

1. Connect FTDI programmer to ESP32-CAM as shown above
2. **Connect IO0 to GND** (critical for flash mode)
3. Plug FTDI into computer USB

### Step 2: Select Port

1. Go to **Tools** → **Port**
2. Select the FTDI COM port

### Step 3: Upload

1. Open `cam_firmware/cam_firmware.ino`
2. Click **Verify** to compile
3. Click **Upload**
4. Wait for "Done uploading"

### Troubleshooting Upload

**"Failed to connect to ESP32-CAM"**
- Ensure IO0 is connected to GND
- Press and hold the small RST button on ESP32-CAM
- Try a different baud rate (115200 or 921600)
- Check FTDI drivers are installed

**"Brownout detector triggered"**
- Use a better 5V power supply
- The ESP32-CAM needs more current during flash
- Add a 100µF capacitor between 5V and GND

**"Invalid header" or "Wrong boot mode"**
- IO0 must be connected to GND during upload
- Disconnect camera module during flashing (optional)

---

## Post-Flash Setup

### Step 1: Disconnect IO0 from GND

After successful upload:
1. Disconnect the wire from IO0 to GND
2. Press the RST button or repower

### Step 2: Verify Operation

1. Open Serial Monitor at **115200** baud
2. You should see: `CAM:READY`
3. If you see `CAM:ERROR`, check camera ribbon cable connection

---

## Camera Module Connection

### OV2640 Camera Ribbon Cable

The camera ribbon cable must be inserted correctly:

1. **Unlock** the connector by pulling the black tab up slightly
2. Insert the ribbon cable with **contacts facing down** (toward the board)
3. **Lock** the connector by pushing the black tab down

```
        ┌──────────────────┐
        │   ESP32-CAM      │
        │                  │
        │  ┌────────────┐  │
        │  │ CAMERA     │  │
        │  │ CONNECTOR  │  │
        │  │   ║║║║║║║   │  │  ← Ribbon cable inserted here
        │  └────────────┘  │
        │                  │
        └──────────────────┘
```

---

## Pin Connections Reference

### ESP32-CAM to ESP32-S3 (Rover Main)

| ESP32-CAM Pin | ESP32-S3 GPIO | Function |
|---|---|---|
| U0T (TX) | GPIO 17 (RX) | UART TX to S3 |
| U0R (RX) | GPIO 18 (TX) | UART RX from S3 |
| 5V | 5V (Buck Converter) | Power |
| GND | GND | Common Ground |

### ESP32-CAM Camera Pins (Internal - AI Thinker)

| Pin | GPIO | Function |
|-----|---|---|
| D0 | 5 | Camera Data Bit 0 (Y2) |
| D1 | 18 | Camera Data Bit 1 (Y3) |
| D2 | 19 | Camera Data Bit 2 (Y4) |
| D3 | 21 | Camera Data Bit 3 (Y5) |
| D4 | 36 | Camera Data Bit 4 (Y6) |
| D5 | 39 | Camera Data Bit 5 (Y7) |
| D6 | 34 | Camera Data Bit 6 (Y8) |
| D7 | 35 | Camera Data Bit 7 (Y9) |
| XCLK | 0 | Camera Clock |
| PCLK | 22 | Pixel Clock |
| VSYNC | 25 | Vertical Sync |
| HREF | 23 | Horizontal Reference |
| SDA | 26 | I2C Data (SIOD) |
| SCL | 27 | I2C Clock (SIOC) |
| PWDN | 32 | Power Down |
| RESET | -1 | Reset (not connected) |

### Status LED

| Pin | GPIO | Function |
|-----|---|---|
| LED | 4 | Status LED (built-in) |

---

## Communication Protocol

### Commands from ESP32-S3

| Command | Code | Description |
|---|---|---|
| `CMD_CAPTURE` | 0x01 | Take single image and return detection result |
| `CMD_STREAM_ON` | 0x02 | Start continuous frame streaming |
| `CMD_STREAM_OFF` | 0x03 | Stop streaming |
| `CMD_DETECT` | 0x04 | Run detection and return result |

### Response Format

The ESP32-CAM sends back a `DetectionResult` struct:

```cpp
typedef struct __attribute__((packed)) {
  bool  fire;        // Fire detected
  bool  motion;      // Motion detected
  bool  human;       // Human detected
  float confidence;  // Detection confidence (0-100)
  char  description[24];  // Human-readable description
} DetectionResult;
```

### Text Responses

- `HAZARD:FIRE` - Fire detected
- `HAZARD:MOTION` - Motion detected
- `HAZARD:HUMAN` - Human detected
- `CLEAR` - No hazards detected
- `CAM:READY` - Camera initialized successfully
- `CAM:ERROR` - Camera initialization failed

---

## Detection Features

### Fire Detection
- RGB565 color space analysis for fire colors
- Thresholds:
  - Red channel minimum: 25
  - Green channel minimum: 10
  - Blue channel maximum: 8
- Minimum fire pixels to trigger: 15

### Motion Detection
- Frame differencing with adaptive threshold
- Previous frame comparison for movement detection
- Motion sensitivity threshold: 4000 (pixel difference)
- Minimum motion pixels to trigger: 30

### Human Detection
- Skin-tone color analysis in RGB565 space
- Simplified pattern recognition
- Higher threshold to reduce false positives

---

## Detection Thresholds (Configurable)

```cpp
#define FIRE_PIXEL_THRESHOLD    15    // Minimum fire pixels to trigger
#define MOTION_PIXEL_THRESHOLD  30    // Minimum motion pixels to trigger
#define MOTION_SENSITIVITY      4000  // Pixel difference threshold
#define FIRE_R_MIN              25    // Red channel minimum for fire
#define FIRE_G_MIN              10    // Green channel minimum for fire
#define FIRE_B_MAX              8     // Blue channel maximum for fire
```

---

## Camera Configuration

The camera is configured for optimal detection performance:

| Setting | Value | Description |
|---|---|---|
| Pixel Format | RGB565 | Efficient for color analysis |
| Frame Size | QVGA (320x240) | Faster processing |
| JPEG Quality | 12 | Compression quality |
| Frame Buffer Count | 2 | Double buffer for streaming |
| XCLK Frequency | 20MHz | Camera clock speed |

---

## Testing After Upload

### Serial Monitor Test

1. Open Serial Monitor at **115200** baud
2. Power on ESP32-CAM
3. Look for `CAM:READY` message

### Manual Command Test

Send these bytes via Serial Monitor (set to "HEX" mode):
- Send `01` (CAPTURE) - should return detection result
- Send `02` (STREAM_ON) - should start streaming
- Send `03` (STREAM_OFF) - should stop streaming
- Send `04` (DETECT) - should return detection result

### LED Indicators

| LED State | Meaning |
|---|---|
| Blinks at startup | Camera initializing |
| Solid on briefly | Camera ready |
| Continuous fast blink | Camera error |
| Brief flash | Image captured |

---

## Power Requirements

| State | Current |
|---|---|
| Idle | ~80mA |
| Streaming | ~150mA |
| Flash LED on | ~300mA+ |

**Note**: The built-in flash LED can draw significant current. Use sparingly for battery operation.

---

## Troubleshooting

### Camera Not Initializing (CAM:ERROR)

1. Check ribbon cable connection
2. Ensure ribbon cable contacts face down
3. Try reseating the ribbon cable
4. Check for damaged ribbon cable

### Poor Image Quality

1. Clean the camera lens
2. Adjust lighting conditions
3. The OV2640 struggles in low light
4. Ensure adequate lighting for detection

### Detection Not Working

1. Ensure adequate lighting
2. Fire detection needs bright orange/red colors
3. Motion detection needs contrast in scene
4. Adjust thresholds in firmware if needed

### Brownout During Operation

1. Ensure stable 5V power supply
2. Add decoupling capacitor
3. Check current capacity of power source

---

## Alternative: Espressif Flash Tool

If Arduino IDE doesn't work, you can use the official Espressif Flash Download Tool:

### Step 1: Compile to Binary

1. In Arduino IDE, enable "Show verbose output during compilation"
2. Compile the sketch
3. Find the `.bin` file path in the output

### Step 2: Download Flash Tool

Download from: https://www.espressif.com/en/support/download/other-tools

### Step 3: Configure

| Setting | Value |
|---|---|
| Chip Type | ESP32 |
| Work Mode | Develop |
| Load Address | 0x10000 |
| SPI Speed | 40MHz |
| SPI Mode | DIO |

### Step 4: Flash

1. Select the compiled `.bin` file
2. Set COM port
3. Click **START**

---

## Next Steps

After flashing the ESP32-CAM:
1. Connect to ESP32-S3 via UART (GPIO 17/18)
2. Flash the [ESP32-S3 rover](./ESP32-S3_INSTRUCTIONS.md)
3. Test camera commands from the rover
4. Review the complete [wiring diagram](./WIRING_DIAGRAMS.md)

---

*Document Version: 2.1*  
*Last Updated: February 2026*

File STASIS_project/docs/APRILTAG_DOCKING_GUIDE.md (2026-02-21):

# AprilTag Docking Guide

## Overview

AprilTag docking allows the Stasis rover to automatically align with a charging station using visual markers. This guide explains how to set up and use the AprilTag docking system.

## Architecture

The C3 acts as a **GPIO extender** for the RPi0W, connecting only to the bottom row of the RPi0W GPIO header (pins 2, 4, 6, 8, 10...). The docking data flow is:

```
ESP32-CAM → ESP32-S3 → ESP32-C3 → RPi0W → Processing → Commands → ESP32-S3
   (detect)    (relay)    (bridge)   (process)   (decide)     (execute)
```

### Key Components

| Component | Role | Connection |
|---|---|---|
| ESP32-CAM | AprilTag detection | Connected to ESP32-S3 via UART2 |
| ESP32-S3 | Rover controller | Receives tag data, relays to C3 via ESP-NOW |
| ESP32-C3 | GPIO extender/bridge | Connects to RPi0W bottom row pins (8, 10) |
| RPi0W | Main processor | Processes AprilTag data, makes decisions |
| LCD 16x2 | Status display | Connected to C3 GPIO 4 (SDA), GPIO 5 (SCL) |

---

## Hardware Setup

### 1. AprilTag Placement

- **Tag Family:** tag36h11 (recommended)
- **Tag ID:** 0 (default for primary docking station)
- **Size:** 100mm x 100mm minimum for 1-2 meter detection
- **Mounting:** 
  - At charging station entrance
  - 30-50cm from ground level
  - Perpendicular to rover approach path
  - Ensure good lighting for detection

### 2. Printing AprilTags

Download AprilTags from: https://github.com/AprilRobotics/apriltag-imgs

**Recommended print settings:**
- High contrast (black on white)
- Matte paper to reduce glare
- Laminate for durability
- Border of at least 1 tag width around the tag

### 3. ESP32-CAM Configuration

The ESP32-CAM should be configured with the AprilTag detection firmware:

1. Flash `cam_firmware.ino` to ESP32-CAM
2. Configure UART2 connection to ESP32-S3:
   - TX → S3 GPIO 16 (RX2)
   - RX ← S3 GPIO 17 (TX2)
3. Set detection parameters in firmware

### 4. C3 to RPi0W Connection (Bottom Row Only)

```
RPi0W GPIO Header (Bottom Row - Outer Edge):
┌─────────────────────────────────────────┐
│ Pin 2  │ Pin 4  │ Pin 6  │ Pin 8  │ Pin 10 │
│  5V    │  5V    │  GND   │ TXD    │  RXD   │
│   │    │   │    │   │    │   │    │   │    │
│   └────┴───┴────┴───┴────┴───┴────┴───┘    │
│              │       │       │            │
│           GND      GPIO20  GPIO21         │
│           (C3)     (C3)    (C3)           │
└─────────────────────────────────────────┘
```

| ESP32-C3 | RPi Zero Pin | Function |
|---|---|---|
| GPIO 21 (TX) | Pin 10 (RXD) | UART TX to Pi |
| GPIO 20 (RX) | Pin 8 (TXD) | UART RX from Pi |
| 5V | Pin 2 (5V) | Power from Pi |
| GND | Pin 6 (GND) | Common Ground |

### 5. LCD Display Connection (to C3)

| ESP32-C3 | LCD Module | Function |
|---|---|---|
| GPIO 4 | SDA | I2C Data |
| GPIO 5 | SCL | I2C Clock |
| 3.3V | VCC | Power |
| GND | GND | Ground |

---

## AprilTag Data Format

### Detection Data

The ESP32-CAM sends detected tag data to the ESP32-S3, which relays it to the C3:

```json
{
  "type": "apriltag",
  "id": 0,
  "cx": 160,
  "cy": 120,
  "distance": 1.5,
  "angle": 5.2
}
```

| Field | Type | Description |
|---|---|---|
| type | string | Always "apriltag" |
| id | int | AprilTag ID (0-30 for tag36h11) |
| cx | int | Center X position (0-320 pixels) |
| cy | int | Center Y position (0-240 pixels) |
| distance | float | Estimated distance in meters |
| angle | float | Angle offset in degrees |

### Alignment Calculations

The RPi0W processes the tag data to determine alignment:

```python
# Image center is (160, 120) for 320x240 resolution
CENTER_X = 160
TOLERANCE = 20  # pixels

def calculate_alignment(cx):
    """Calculate turn direction based on tag position."""
    offset = cx - CENTER_X
    
    if abs(offset) < TOLERANCE:
        return "ALIGNED"
    elif offset < 0:
        return "TURN_LEFT"
    else:
        return "TURN_RIGHT"
```

---

## Docking Procedure

### Phase 1: Approach

1. RPi0W sends `DOCK` command to rover
2. Rover switches to docking mode
3. ESP32-CAM activates AprilTag detection
4. Rover moves slowly toward charging station

### Phase 2: Alignment

1. RPi0W receives AprilTag data via C3 bridge
2. Calculates alignment corrections:
   - `cx < 140`: Turn left
   - `cx > 180`: Turn right
   - `cx` in range 140-180: Aligned
3. Sends turn commands to rover
4. Repeats until aligned

### Phase 3: Final Approach

1. While aligned, move forward slowly
2. Monitor distance decreasing
3. Stop when distance < 0.3m
4. Fine-tune alignment if needed

### Phase 4: Docking Complete

1. Rover makes electrical contact with charger
2. Charging begins automatically
3. LCD displays "CHARGING"
4. Rover enters sleep mode

---

## Python Implementation

### station_monitor.py Functions

The base station monitor includes these AprilTag processing functions:

```python
from dataclasses import dataclass
from typing import Optional

@dataclass
class AprilTagData:
    """AprilTag detection data."""
    tag_id: int
    cx: int           # Center X (0-320)
    cy: int           # Center Y (0-240)
    distance: float   # Estimated distance in meters
    angle: float      # Angle offset in degrees

def process_apriltag_for_docking(tag_data: dict) -> dict:
    """
    Process AprilTag detection and calculate alignment commands.
    
    Args:
        tag_data: Dict with 'id', 'cx', 'cy', 'distance', 'angle'
    
    Returns:
        Dict with alignment information:
        {
            'turn_direction': 'LEFT' | 'RIGHT' | 'NONE',
            'turn_amount': float (0-100),
            'move_forward': bool,
            'aligned': bool,
            'distance': float
        }
    """
    CENTER_X = 160
    TOLERANCE = 20
    
    cx = tag_data.get('cx', 160)
    distance = tag_data.get('distance', 0)
    
    offset = cx - CENTER_X
    
    if abs(offset) < TOLERANCE:
        return {
            'turn_direction': 'NONE',
            'turn_amount': 0,
            'move_forward': True,
            'aligned': True,
            'distance': distance
        }
    elif offset < 0:
        return {
            'turn_direction': 'LEFT',
            'turn_amount': min(abs(offset) / 160 * 100, 100),
            'move_forward': False,
            'aligned': False,
            'distance': distance
        }
    else:
        return {
            'turn_direction': 'RIGHT',
            'turn_amount': min(offset / 160 * 100, 100),
            'move_forward': False,
            'aligned': False,
            'distance': distance
        }

def send_alignment_commands(alignment: dict, serial_conn) -> None:
    """
    Send alignment commands to rover via C3 bridge.
    
    Args:
        alignment: Dict from process_apriltag_for_docking()
        serial_conn: Serial connection to C3
    """
    if alignment['turn_direction'] == 'LEFT':
        cmd = f"TURN_LEFT:{alignment['turn_amount']:.0f}"
    elif alignment['turn_direction'] == 'RIGHT':
        cmd = f"TURN_RIGHT:{alignment['turn_amount']:.0f}"
    elif alignment['move_forward']:
        cmd = "FORWARD:30"
    else:
        cmd = "STOP"
    
    serial_conn.write(f"{cmd}\n".encode())

def send_lcd_command(serial_conn, line: int, text: str) -> None:
    """
    Send LCD display command to C3.
    
    Args:
        serial_conn: Serial connection to C3
        line: Line number (1 or 2)
        text: Text to display (max 16 chars)
    """
    cmd = f"LCD:L{line}:{text[:16]}\n"
    serial_conn.write(cmd.encode())

def display_docking_status(serial_conn, status: str, distance: float) -> None:
    """
    Show docking progress on LCD via C3.
    
    Args:
        serial_conn: Serial connection to C3
        status: Status string
        distance: Distance in meters
    """
    send_lcd_command(serial_conn, 1, f"{status}")
    
    # Create progress bar
    progress = max(0, min(5, int((2.0 - distance) / 2.0 * 5)))
    bar = '▓' * progress + '░' * (5 - progress)
    send_lcd_command(serial_conn, 2, f"D:{distance:.1f}m {bar}")

def handle_docking_sequence(serial_conn, tag_data: dict) -> bool:
    """
    Complete docking sequence handler.
    
    Args:
        serial_conn: Serial connection to C3
        tag_data: AprilTag detection data
    
    Returns:
        True if docking successful, False otherwise
    """
    alignment = process_apriltag_for_docking(tag_data)
    
    # Update LCD
    display_docking_status(serial_conn, "DOCKING", alignment['distance'])
    
    # Check if close enough
    if alignment['distance'] < 0.3 and alignment['aligned']:
        send_lcd_command(serial_conn, 1, "DOCKED!")
        send_lcd_command(serial_conn, 2, "CHARGING...")
        return True
    
    # Send alignment commands
    send_alignment_commands(alignment, serial_conn)
    
    return False
```

---

## LCD Display Messages

### During Docking

```
Line 1: DOCKING...
Line 2: D:0.8m ▓▓▓░░
```

### Status Messages

| Status | Line 1 | Line 2 |
|---|---|---|
| Approaching | APPROACHING | D:X.Xm ▓░░░░ |
| Aligning | ALIGNING... | Turn: LEFT/RIGHT |
| Aligned | ALIGNED | D:X.Xm ▓▓▓░░ |
| Docked | DOCKED! | CHARGING... |
| Charging | CHARGING | Bat: XX% |
| Failed | DOCK_FAIL | No tag found |

---

## Troubleshooting

### AprilTag Not Detected

1. **Check lighting:** Ensure adequate illumination at docking station
2. **Check tag visibility:** Tag should be clean and undamaged
3. **Check camera angle:** ESP32-CAM should have clear view
4. **Check distance:** Tag may be too far or too close
5. **Check tag family:** Ensure firmware uses tag36h11

### Alignment Issues

1. **Oscillating left/right:** Increase TOLERANCE value
2. **Not centering:** Check camera mounting angle
3. **Slow response:** Reduce approach speed
4. **Overshooting:** Add deceleration near target

### Communication Issues

1. **No data from C3:** Check UART connections (pins 8, 10)
2. **No data from S3:** Check ESP-NOW pairing
3. **No data from CAM:** Check UART2 connections to S3

### LCD Not Working

1. **No display:** Check I2C connections (GPIO 4, 5)
2. **Wrong characters:** Check I2C address (0x27 or 0x3F)
3. **Dim display:** Check backlight connection

---

## Testing

### Manual Test

1. Place AprilTag 1 meter from rover
2. Run docking command from base station
3. Observe rover behavior:
   - Should detect tag
   - Should align to center
   - Should approach slowly
   - Should stop at 30cm

### LCD Test

```python
import serial

s = serial.Serial('/dev/serial0', 115200)

# Test LCD commands
s.write(b'LCD:CLEAR\n')
s.write(b'LCD:L1:Test Line 1\n')
s.write(b'LCD:L2:Test Line 2\n')
```

### AprilTag Simulation Test

```python
# Simulate AprilTag data
test_data = {
    'id': 0,
    'cx': 180,      # Slightly right of center
    'cy': 120,
    'distance': 1.5,
    'angle': 3.0
}

result = process_apriltag_for_docking(test_data)
print(result)
# Output: {'turn_direction': 'RIGHT', 'turn_amount': 12.5, ...}
```

---

## Advanced Configuration

### Multiple AprilTags

For multiple docking stations, use different tag IDs:

```python
DOCKING_STATIONS = {
    0: {'name': 'Station A', 'x': 0, 'y': 0},
    1: {'name': 'Station B', 'x': 10, 'y': 0},
    2: {'name': 'Station C', 'x': 0, 'y': 10},
}

def get_station_info(tag_id):
    return DOCKING_STATIONS.get(tag_id)
```

### Custom Alignment Parameters

```python
# Adjust these for your rover
ALIGNMENT_CONFIG = {
    'center_x': 160,        # Image center X
    'center_y': 120,        # Image center Y
    'tolerance': 20,        # Alignment tolerance (pixels)
    'min_distance': 0.3,    # Minimum approach distance (m)
    'max_distance': 2.0,    # Maximum detection distance (m)
    'approach_speed': 30,   # Approach speed (0-100)
    'turn_speed': 20,       # Turn speed (0-100)
}
```

---

## Related Documentation

- [ESP32-C3 Instructions](./ESP32-C3_INSTRUCTIONS.md) - C3 setup and configuration
- [ESP32-CAM Instructions](./ESP32-CAM_INSTRUCTIONS.md) - Camera firmware setup
- [ESP32-S3 Instructions](./ESP32-S3_INSTRUCTIONS.md) - Rover controller setup
- [Wiring Diagrams](./WIRING_DIAGRAMS.md) - Complete wiring reference
- [RPI0 Instructions](./RPI0_INSTRUCTIONS.md) - Raspberry Pi Zero setup

---

*Document Version: 1.0*  
*Last Updated: February 2026*  
*For GPIO extender architecture with bottom-row-only RPi0W connection*
## Overview

AprilTag docking allows the Stasis rover to automatically align with a charging station using visual markers. This guide explains how to set up and use the AprilTag docking system.

## Architecture

The C3 acts as a **GPIO extender** for the RPi0W, connecting only to the bottom row of the RPi0W GPIO header (pins 2, 4, 6, 8, 10...). The docking data flow is:

```
ESP32-CAM → ESP32-S3 → ESP32-C3 → RPi0W → Processing → Commands → ESP32-S3
   (detect)    (relay)    (bridge)   (process)   (decide)     (execute)
```

### Key Components

| Component | Role | Connection |
|---|---|---|
| ESP32-CAM | AprilTag detection | Connected to ESP32-S3 via UART2 |
| ESP32-S3 | Rover controller | Receives tag data, relays to C3 via ESP-NOW |
| ESP32-C3 | GPIO extender/bridge | Connects to RPi0W bottom row pins (8, 10) |
| RPi0W | Main processor | Processes AprilTag data, makes decisions |
| LCD 16x2 | Status display | Connected to C3 GPIO 4 (SDA), GPIO 5 (SCL) |

---

## Hardware Setup

### 1. AprilTag Placement

- **Tag Family:** tag36h11 (recommended)
- **Tag ID:** 0 (default for primary docking station)
- **Size:** 100mm x 100mm minimum for 1-2 meter detection
- **Mounting:** 
  - At charging station entrance
  - 30-50cm from ground level
  - Perpendicular to rover approach path
  - Ensure good lighting for detection

### 2. Printing AprilTags

Download AprilTags from: https://github.com/AprilRobotics/apriltag-imgs

**Recommended print settings:**
- High contrast (black on white)
- Matte paper to reduce glare
- Laminate for durability
- Border of at least 1 tag width around the tag

### 3. ESP32-CAM Configuration

The ESP32-CAM should be configured with the AprilTag detection firmware:

1. Flash `cam_firmware.ino` to ESP32-CAM
2. Configure UART2 connection to ESP32-S3:
   - TX → S3 GPIO 16 (RX2)
   - RX ← S3 GPIO 17 (TX2)
3. Set detection parameters in firmware

### 4. C3 to RPi0W Connection (Bottom Row Only)

```
RPi0W GPIO Header (Bottom Row - Outer Edge):
┌─────────────────────────────────────────┐
│ Pin 2  │ Pin 4  │ Pin 6  │ Pin 8  │ Pin 10 │
│  5V    │  5V    │  GND   │ TXD    │  RXD   │
│   │    │   │    │   │    │   │    │   │    │
│   └────┴───┴────┴───┴────┴───┴────┴───┘    │
│              │       │       │            │
│           GND      GPIO20  GPIO21         │
│           (C3)     (C3)    (C3)           │
└─────────────────────────────────────────┘
```

| ESP32-C3 | RPi Zero Pin | Function |
|---|---|---|
| GPIO 21 (TX) | Pin 10 (RXD) | UART TX to Pi |
| GPIO 20 (RX) | Pin 8 (TXD) | UART RX from Pi |
| 5V | Pin 2 (5V) | Power from Pi |
| GND | Pin 6 (GND) | Common Ground |

### 5. LCD Display Connection (to C3)

| ESP32-C3 | LCD Module | Function |
|---|---|---|
| GPIO 4 | SDA | I2C Data |
| GPIO 5 | SCL | I2C Clock |
| 3.3V | VCC | Power |
| GND | GND | Ground |

---

## AprilTag Data Format

### Detection Data

The ESP32-CAM sends detected tag data to the ESP32-S3, which relays it to the C3:

```json
{
  "type": "apriltag",
  "id": 0,
  "cx": 160,
  "cy": 120,
  "distance": 1.5,
  "angle": 5.2
}
```

| Field | Type | Description |
|---|---|---|
| type | string | Always "apriltag" |
| id | int | AprilTag ID (0-30 for tag36h11) |
| cx | int | Center X position (0-320 pixels) |
| cy | int | Center Y position (0-240 pixels) |
| distance | float | Estimated distance in meters |
| angle | float | Angle offset in degrees |

### Alignment Calculations

The RPi0W processes the tag data to determine alignment:

```python
# Image center is (160, 120) for 320x240 resolution
CENTER_X = 160
TOLERANCE = 20  # pixels

def calculate_alignment(cx):
    """Calculate turn direction based on tag position."""
    offset = cx - CENTER_X
    
    if abs(offset) < TOLERANCE:
        return "ALIGNED"
    elif offset < 0:
        return "TURN_LEFT"
    else:
        return "TURN_RIGHT"
```

---

## Docking Procedure

### Phase 1: Approach

1. RPi0W sends `DOCK` command to rover
2. Rover switches to docking mode
3. ESP32-CAM activates AprilTag detection
4. Rover moves slowly toward charging station

### Phase 2: Alignment

1. RPi0W receives AprilTag data via C3 bridge
2. Calculates alignment corrections:
   - `cx < 140`: Turn left
   - `cx > 180`: Turn right
   - `cx` in range 140-180: Aligned
3. Sends turn commands to rover
4. Repeats until aligned

### Phase 3: Final Approach

1. While aligned, move forward slowly
2. Monitor distance decreasing
3. Stop when distance < 0.3m
4. Fine-tune alignment if needed

### Phase 4: Docking Complete

1. Rover makes electrical contact with charger
2. Charging begins automatically
3. LCD displays "CHARGING"
4. Rover enters sleep mode

---

## Python Implementation

### station_monitor.py Functions

The base station monitor includes these AprilTag processing functions:

```python
from dataclasses import dataclass
from typing import Optional

@dataclass
class AprilTagData:
    """AprilTag detection data."""
    tag_id: int
    cx: int           # Center X (0-320)
    cy: int           # Center Y (0-240)
    distance: float   # Estimated distance in meters
    angle: float      # Angle offset in degrees

def process_apriltag_for_docking(tag_data: dict) -> dict:
    """
    Process AprilTag detection and calculate alignment commands.
    
    Args:
        tag_data: Dict with 'id', 'cx', 'cy', 'distance', 'angle'
    
    Returns:
        Dict with alignment information:
        {
            'turn_direction': 'LEFT' | 'RIGHT' | 'NONE',
            'turn_amount': float (0-100),
            'move_forward': bool,
            'aligned': bool,
            'distance': float
        }
    """
    CENTER_X = 160
    TOLERANCE = 20
    
    cx = tag_data.get('cx', 160)
    distance = tag_data.get('distance', 0)
    
    offset = cx - CENTER_X
    
    if abs(offset) < TOLERANCE:
        return {
            'turn_direction': 'NONE',
            'turn_amount': 0,
            'move_forward': True,
            'aligned': True,
            'distance': distance
        }
    elif offset < 0:
        return {
            'turn_direction': 'LEFT',
            'turn_amount': min(abs(offset) / 160 * 100, 100),
            'move_forward': False,
            'aligned': False,
            'distance': distance
        }
    else:
        return {
            'turn_direction': 'RIGHT',
            'turn_amount': min(offset / 160 * 100, 100),
            'move_forward': False,
            'aligned': False,
            'distance': distance
        }

def send_alignment_commands(alignment: dict, serial_conn) -> None:
    """
    Send alignment commands to rover via C3 bridge.
    
    Args:
        alignment: Dict from process_apriltag_for_docking()
        serial_conn: Serial connection to C3
    """
    if alignment['turn_direction'] == 'LEFT':
        cmd = f"TURN_LEFT:{alignment['turn_amount']:.0f}"
    elif alignment['turn_direction'] == 'RIGHT':
        cmd = f"TURN_RIGHT:{alignment['turn_amount']:.0f}"
    elif alignment['move_forward']:
        cmd = "FORWARD:30"
    else:
        cmd = "STOP"
    
    serial_conn.write(f"{cmd}\n".encode())

def send_lcd_command(serial_conn, line: int, text: str) -> None:
    """
    Send LCD display command to C3.
    
    Args:
        serial_conn: Serial connection to C3
        line: Line number (1 or 2)
        text: Text to display (max 16 chars)
    """
    cmd = f"LCD:L{line}:{text[:16]}\n"
    serial_conn.write(cmd.encode())

def display_docking_status(serial_conn, status: str, distance: float) -> None:
    """
    Show docking progress on LCD via C3.
    
    Args:
        serial_conn: Serial connection to C3
        status: Status string
        distance: Distance in meters
    """
    send_lcd_command(serial_conn, 1, f"{status}")
    
    # Create progress bar
    progress = max(0, min(5, int((2.0 - distance) / 2.0 * 5)))
    bar = '▓' * progress + '░' * (5 - progress)
    send_lcd_command(serial_conn, 2, f"D:{distance:.1f}m {bar}")

def handle_docking_sequence(serial_conn, tag_data: dict) -> bool:
    """
    Complete docking sequence handler.
    
    Args:
        serial_conn: Serial connection to C3
        tag_data: AprilTag detection data
    
    Returns:
        True if docking successful, False otherwise
    """
    alignment = process_apriltag_for_docking(tag_data)
    
    # Update LCD
    display_docking_status(serial_conn, "DOCKING", alignment['distance'])
    
    # Check if close enough
    if alignment['distance'] < 0.3 and alignment['aligned']:
        send_lcd_command(serial_conn, 1, "DOCKED!")
        send_lcd_command(serial_conn, 2, "CHARGING...")
        return True
    
    # Send alignment commands
    send_alignment_commands(alignment, serial_conn)
    
    return False
```

---

## LCD Display Messages

### During Docking

```
Line 1: DOCKING...
Line 2: D:0.8m ▓▓▓░░
```

### Status Messages

| Status | Line 1 | Line 2 |
|---|---|---|
| Approaching | APPROACHING | D:X.Xm ▓░░░░ |
| Aligning | ALIGNING... | Turn: LEFT/RIGHT |
| Aligned | ALIGNED | D:X.Xm ▓▓▓░░ |
| Docked | DOCKED! | CHARGING... |
| Charging | CHARGING | Bat: XX% |
| Failed | DOCK_FAIL | No tag found |

---

## Troubleshooting

### AprilTag Not Detected

1. **Check lighting:** Ensure adequate illumination at docking station
2. **Check tag visibility:** Tag should be clean and undamaged
3. **Check camera angle:** ESP32-CAM should have clear view
4. **Check distance:** Tag may be too far or too close
5. **Check tag family:** Ensure firmware uses tag36h11

### Alignment Issues

1. **Oscillating left/right:** Increase TOLERANCE value
2. **Not centering:** Check camera mounting angle
3. **Slow response:** Reduce approach speed
4. **Overshooting:** Add deceleration near target

### Communication Issues

1. **No data from C3:** Check UART connections (pins 8, 10)
2. **No data from S3:** Check ESP-NOW pairing
3. **No data from CAM:** Check UART2 connections to S3

### LCD Not Working

1. **No display:** Check I2C connections (GPIO 4, 5)
2. **Wrong characters:** Check I2C address (0x27 or 0x3F)
3. **Dim display:** Check backlight connection

---

## Testing

### Manual Test

1. Place AprilTag 1 meter from rover
2. Run docking command from base station
3. Observe rover behavior:
   - Should detect tag
   - Should align to center
   - Should approach slowly
   - Should stop at 30cm

### LCD Test

```python
import serial

s = serial.Serial('/dev/serial0', 115200)

# Test LCD commands
s.write(b'LCD:CLEAR\n')
s.write(b'LCD:L1:Test Line 1\n')
s.write(b'LCD:L2:Test Line 2\n')
```

### AprilTag Simulation Test

```python
# Simulate AprilTag data
test_data = {
    'id': 0,
    'cx': 180,      # Slightly right of center
    'cy': 120,
    'distance': 1.5,
    'angle': 3.0
}

result = process_apriltag_for_docking(test_data)
print(result)
# Output: {'turn_direction': 'RIGHT', 'turn_amount': 12.5, ...}
```

---

## Advanced Configuration

### Multiple AprilTags

For multiple docking stations, use different tag IDs:

```python
DOCKING_STATIONS = {
    0: {'name': 'Station A', 'x': 0, 'y': 0},
    1: {'name': 'Station B', 'x': 10, 'y': 0},
    2: {'name': 'Station C', 'x': 0, 'y': 10},
}

def get_station_info(tag_id):
    return DOCKING_STATIONS.get(tag_id)
```

### Custom Alignment Parameters

```python
# Adjust these for your rover
ALIGNMENT_CONFIG = {
    'center_x': 160,        # Image center X
    'center_y': 120,        # Image center Y
    'tolerance': 20,        # Alignment tolerance (pixels)
    'min_distance': 0.3,    # Minimum approach distance (m)
    'max_distance': 2.0,    # Maximum detection distance (m)
    'approach_speed': 30,   # Approach speed (0-100)
    'turn_speed': 20,       # Turn speed (0-100)
}
```

---

## Related Documentation

- [ESP32-C3 Instructions](./ESP32-C3_INSTRUCTIONS.md) - C3 setup and configuration
- [ESP32-CAM Instructions](./ESP32-CAM_INSTRUCTIONS.md) - Camera firmware setup
- [ESP32-S3 Instructions](./ESP32-S3_INSTRUCTIONS.md) - Rover controller setup
- [Wiring Diagrams](./WIRING_DIAGRAMS.md) - Complete wiring reference
- [RPI0 Instructions](./RPI0_INSTRUCTIONS.md) - Raspberry Pi Zero setup

---

*Document Version: 1.0*  
*Last Updated: February 2026*  
*For GPIO extender architecture with bottom-row-only RPi0W connection*

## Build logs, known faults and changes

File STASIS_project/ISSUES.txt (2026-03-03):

================================================================================
STASIS ROVER - KNOWN ISSUES & RISKS
================================================================================

This document lists known issues, potential risks, and areas requiring attention
in the STASIS rover firmware.

================================================================================
1. MINOR ISSUES (Low Priority)
================================================================================

1.1 Global Variables Not Volatile
----------------------------------
Issue: latitude, longitude, currentState, batteryVoltage, distance are used 
       across FreeRTOS tasks but not declared volatile.
Risk: LOW - On ESP32, float reads/writes are atomic. Compiler may optimize
      but unlikely to cause issues in short demos.
Fix: Add 'volatile' prefix if desired:
     volatile float latitude;
     volatile float longitude;
     volatile RoverState currentState;

1.2 String Class in GPS Parsing
-------------------------------
Issue: Uses String class (gpsBuffer) which can fragment heap over time.
Risk: LOW - Buffer is limited to 100 chars and reused. Unlikely to cause
      problems in typical demo duration.
Fix: Use fixed char array if needed.

1.3 delay(100) in safeSendSMS
-----------------------------
Issue: Still uses delay(100) for SIM800 rail stabilization.
Risk: NONE - This is intentional - SIM800 needs stable power before sending.
      Only runs during SMS, not during normal operation.

================================================================================
2. CONFIGURATION CONSTANTS (May Need Tuning)
================================================================================

2.1 Ultrasonic Timeout
---------------------
#define ULTRASONIC_TIMEOUT_US 30000  // 30ms
Note: Current setting prevents 1-second freeze. May need adjustment if
      max distance requirements change.

2.2 Dock Detection
-----------------
#define DOCK_VOLTAGE_RISE    0.4    // 0.4V above baseline
#define DOCK_CONFIRM_TIME_MS 2000   // 2 seconds
#define DOCK_DEBOUNCE_FRAMES 20     // 20 frames

Note: These values are tuned for 2S Li-ion (7.4V nominal). If using different
battery chemistry, adjust DOCK_VOLTAGE_RISE accordingly.

2.3 GPS Geofence
----------------
#define GEOFENCE_RADIUS_M 50.0    // 50 meter radius
#define GPS_VALID_AGE_MS 10000    // 10 seconds

Note: Adjust GEOFENCE_RADIUS_M based on actual demo area size.

2.4 SMS Cooldown
---------------
#define SMS_COOLDOWN_MS 60000  // 60 seconds

Note: Prevents SMS spam. May want to reduce for testing.

================================================================================
3. HARDWARE-SPECIFIC NOTES
================================================================================

3.1 Pin Assignments
------------------
Verify all pin definitions match actual wiring:
- Motor pins: 2,4,5,6,7,15,16,18
- Ultrasonic: 9,10
- GPS: 8,19
- Battery ADC: 1
- Buzzer: 14
- Status LED: 45
- UART to Pi: 43,44

3.2 Voltage Divider
------------------
Battery ADC assumes 30k+10k divider (ratio 0.25).
Formula: batteryVoltage = adcVoltage / 0.25

If using different divider, adjust this value.

3.3 SIM800 Power
---------------
SIM800 requires separate ~4V high-current rail.
DO NOT power from ESP32 3.3V rail - will brownout.

================================================================================
4. BEHAVIOR NOTES
================================================================================

4.1 First-Time Startup Behavior
-------------------------------
- Dock detection requires ~1 second to establish baseline
- GPS requires 30-60 seconds for first fix (cold start)
- GSM requires 10-30 seconds for network registration

4.2 State Machine Guards
----------------------
- STATE_MIN_TIME_MS = 500ms prevents rapid state flapping
- First state transition has no delay (previousState = currentState at init)

4.3 Motor Ramping
----------------
- SPEED_RAMP_RATE = 5 per cycle (50ms)
- Smooth acceleration/deceleration to prevent voltage spikes

4.4 GPS Dead Zone Behavior
-------------------------
- If GPS fix older than 5 seconds, rover enters SAFE_HALT
- Motors stop immediately
- Must wait for valid GPS before resuming patrol

================================================================================
5. TESTING RECOMMENDATIONS
================================================================================

Before Demo:
1. Test dock detection with actual charging voltage
2. Verify GPS gets fix outdoors (not indoor)
3. Test SIM800 SMS send (with working SIM)
4. Test emergency stop (ESTOP command)
5. Verify motor direction wiring
6. Test geofence breach behavior

================================================================================
6. KNOWN LIMITATIONS
================================================================================

- No WiFi/ESP-NOW in core safety loop (as designed)
- No current sensing on motors (stall detection not implemented)
- Temperature sensor is placeholder (no actual DS18B20 code)
- No automatic home position save to EEPROM

================================================================================
END OF DOCUMENT
================================================================================

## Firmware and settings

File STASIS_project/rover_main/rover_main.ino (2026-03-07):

/**
 * STASIS Rover - Multi-State Autonomous Controller
 * ====================================================
 * ESP32-S3 Main Firmware
 * 
 * Handles: Navigation, Motor Control, Sensor Fusion, State Machine,
 *          Dock Detection, GPS Geofence, Charging Safety
 * 
 * Hardware: ESP32-S3, L9110S motors, DS18B20, HC-SR04, Neo-6M GPS, SIM800L
 * 
 * Author: EdgeCase Team
 */

#include <Arduino.h>
#include <driver/uart.h>
#include <driver/gpio.h>
#include <freertos/FreeRTOS.h>
#include <freertos/task.h>
#include <freertos/queue.h>

// =============================================================================
// HARDWARE CONFIGURATION - Updated for new requirements
// =============================================================================

// Motor Driver Pins (L9110S - 4WD paired)
#define MOTOR_A_PWM    4
#define MOTOR_A_DIR    2
#define MOTOR_B_PWM    5
#define MOTOR_B_DIR    18
#define MOTOR_C_PWM    6
#define MOTOR_C_DIR    7
#define MOTOR_D_PWM    15
#define MOTOR_D_DIR    16

// Sensors
#define ULTRASONIC_TRIG 10
#define ULTRASONIC_ECHO 9
#define ONEWIRE_PIN     21   // DS18B20
#define LDR_PIN         0    // ADC for LDR (light sensor)
#define BUZZER_PIN      14
#define STATUS_LED      45

// GPS (NEO-6M) - SoftwareSerial on ESP32
#define GPS_TX_PIN      8
#define GPS_RX_PIN      19

// SIM800L GSM Module
#define SIM800_TX       13
#define SIM800_RX       12

// Battery Monitor (ADC)
#define BATTERY_ADC     1

// Optional: Dedicated dock detect GPIO (if wired)
// #define DOCK_DETECT_PIN  47  // Uncomment if hardware present

// UART for Pi Zero communication
#define UART_TX_PIN    43
#define UART_RX_PIN    44
#define UART_NUM       UART_NUM_1
#define UART_BAUD      115200

// PWM Configuration
#define PWM_FREQ       1000
#define PWM_RESOLUTION 8

// =============================================================================
// CONFIGURATION
// =============================================================================

// Communication Timeouts
#define COMMAND_TIMEOUT_MS  500   // Stop if no command from Pi
#define ESPNOW_TIMEOUT_MS   1000  // Stop if no ESP-NOW from base

// =============================================================================
// COMMAND PROTOCOL STRUCTURES
// =============================================================================

/**
 * DockCmd: Compact command from Pi Zero for docking
 * Packet format (6 bytes):
 *   [0] HEADER: 0xAA
 *   [1] turn:   int8_t  -100 to +100
 *   [2] speed:  uint8_t 0-100
 *   [3] docked: uint8_t 0 or 1
 *   [4] checksum: XOR of bytes 1-3
 *   [5] TAIL: 0x55
 */
struct DockCommand {
    int8_t turn;       // -100 to +100
    uint8_t speed;     // 0 to 100
    uint8_t docked;    // 0 or 1
    uint8_t checksum;
};

// =============================================================================
// STATE MACHINE DEFINITIONS - Validated for production
// =============================================================================

enum RoverState {
    STATE_SAFE_IDLE = 0,      // Minimal power, sensors active
    STATE_PATROL,             // Autonomous patrol with geofence
    STATE_ALERT,              // Hazard detected - investigating
    STATE_RETURN_TO_BASE,     // Geofence violation or manual recall
    STATE_DOCKING,            // AprilTag precision approach
    STATE_DOCKED_CHARGING     // Passive charging, motors disabled
};

enum AlertType {
    ALERT_NONE = 0,
    ALERT_FIRE,
    ALERT_EARTHQUAKE,
    ALERT_GEOFENCE,
    ALERT_INTRUDER
};

// =============================================================================
// GLOBAL STATE — shared across FreeRTOS tasks
// FIX C5: These were used throughout but never declared, causing compile errors.
// =============================================================================
volatile RoverState currentState    = STATE_SAFE_IDLE;
volatile RoverState previousState   = STATE_SAFE_IDLE;
volatile AlertType  currentAlert    = ALERT_NONE;
volatile bool       estopTriggered  = false;
volatile bool       dockingEnabled  = false;
volatile bool       lowPowerMode    = false;
volatile bool       fireDetected    = false;
volatile bool       humanDetected   = false;
volatile bool       tiltDetected    = false;
volatile bool       alertSent       = false;
volatile bool       alertConfirmed  = false;
volatile int8_t     currentTurn     = 0;
volatile uint8_t    currentSpeed    = 0;
volatile float      latitude        = 0.0f;
volatile float      longitude       = 0.0f;
volatile float      batteryVoltage  = 0.0f;
volatile float      batteryPercent  = 0.0f;
volatile float      distance        = 999.0f;
volatile uint32_t   gpsFixAge       = 60000;
volatile uint32_t   lastCommandTime = 0;
volatile uint32_t   stateEntryTime  = 0;
volatile uint32_t   alertStartTime  = 0;

#define LOW_BATTERY_THRESHOLD  20   // percent — triggers low power mode and return-to-base

// =============================================================================
// DOCK DETECTION MODULE - Robust battery voltage rise detection
// =============================================================================
// Approach: Compare current voltage to baseline, detect sustained rise
// Primary method: Monitor voltage increase when docked (charging raises voltage)
// Debouncing: Require sustained voltage rise for CONFIRM_TIME_MS
// Tolerates: Noisy contact, brief disconnects
// Non-blocking: Uses millis() timing

#define DOCK_VOLTAGE_RISE      0.4    // Minimum voltage rise above baseline (0.4V)
#define DOCK_CONFIRM_TIME_MS   2000   // Must sustain rise for 2 seconds
#define UNDOCK_CONFIRM_MS      1500   // Must be low for 1.5s to confirm undock
#define BASELINE_SAMPLES       10      // Samples to establish baseline
#define DOCK_DEBOUNCE_FRAMES   20      // 20 consecutive frames (2 sec) to confirm dock

struct DockDetector {
    bool isDocked;
    bool wasDocked;
    uint32_t dockStartTime;
    uint32_t undockStartTime;
    float baselineVoltage;
    bool baselineStable;
    uint8_t sampleCount;
    uint8_t dockConfirmCounter;    // Debounce frame counter
    uint8_t undockConfirmCounter;
};

static DockDetector dockState = {
    false, false, 0, 0, 0.0, false, 0, 0, 0
};

/**
 * Robust dock detection using voltage rise above baseline
 * Call every battery update cycle (~100ms)
 * Returns true on rising edge (just docked)
 */
bool detectDock(float currentVoltage) {
    uint32_t now = millis();
    
    // Phase 1: Establish baseline (first 10 samples)
    if (!dockState.baselineStable) {
        if (dockState.sampleCount < BASELINE_SAMPLES) {
            dockState.baselineVoltage += currentVoltage;
            dockState.sampleCount++;
        } else if (dockState.sampleCount == BASELINE_SAMPLES) {
            dockState.baselineVoltage /= BASELINE_SAMPLES;
            dockState.baselineStable = true;
            Serial.print("DOCK: Baseline established at ");
            Serial.print(dockState.baselineVoltage);
            Serial.println("V");
            dockState.sampleCount++;
        }
        return false;
    }
    
    // Phase 2: Monitor for voltage rise (charging)
    float voltageRise = currentVoltage - dockState.baselineVoltage;
    bool voltageRising = (voltageRise >= DOCK_VOLTAGE_RISE);
    
    if (voltageRising) {
        // Reset undock counter, increment dock counter
        dockState.undockConfirmCounter = 0;
        dockState.dockConfirmCounter++;
        
        // Start or continue dock confirmation timer
        if (dockState.undockStartTime > 0) {
            dockState.undockStartTime = 0;
        }
        
        if (dockState.dockStartTime == 0) {
            dockState.dockStartTime = now;
        }
        
        // DOCK DEBOUNCE: Require 20 consecutive frames of voltage rise
        if (dockState.dockConfirmCounter >= DOCK_DEBOUNCE_FRAMES) {
            if (!dockState.isDocked) {
                dockState.isDocked = true;
                dockState.dockStartTime = 0;
                dockState.dockConfirmCounter = 0;
                Serial.print("DOCK: Confirmed at ");
                Serial.print(currentVoltage);
                Serial.print("V (rise: ");
                Serial.print(voltageRise);
                Serial.println("V)");
            }
        }
    } else {
        // Voltage dropped - reset dock counter, increment undock counter
        dockState.dockConfirmCounter = 0;
        dockState.undockConfirmCounter++;
        
        // Start undock timer
        if (dockState.dockStartTime > 0) {
            dockState.dockStartTime = 0;
        }
        
        if (dockState.undockStartTime == 0) {
            dockState.undockStartTime = now;
        }
        
        // Require 20 consecutive frames of low voltage to undock
        if (dockState.undockConfirmCounter >= DOCK_DEBOUNCE_FRAMES) {
            if (dockState.isDocked) {
                dockState.isDocked = false;
                dockState.undockStartTime = 0;
                dockState.undockConfirmCounter = 0;
                dockState.baselineStable = false;  // Reset baseline
                dockState.sampleCount = 0;
                dockState.baselineVoltage = 0;
                Serial.println("DOCK: Undocked - baseline reset");
            }
        }
    }
    
    // Return true on rising edge (just docked)
    bool justDocked = dockState.isDocked && !dockState.wasDocked;
    dockState.wasDocked = dockState.isDocked;
    
    return justDocked;
}

bool isDocked() {
    return dockState.isDocked;
}

// =============================================================================
// GPS GEOFENCE MODULE
// =============================================================================
// Uses flat-earth approximation (acceptable for small areas)
// Stores home position at startup
// Monitors distance from home
// Non-blocking, tolerant of GPS signal loss

#define GEOFENCE_RADIUS_M   50.0    // 50 meter radius
#define GPS_VALID_AGE_MS   10000   // Discard fixes older than 10s

struct GeofenceMonitor {
    float homeLat;
    float homeLon;
    bool homeSet;
    bool violated;
    uint32_t lastValidFix;
    float currentLat;
    float currentLon;
};

static GeofenceMonitor geofence = {
    0.0f, 0.0f, false, false, 0, 0.0f, 0.0f
};

// Flat-earth approximation for small distances
// Returns distance in meters
float calculateDistance(float lat1, float lon1, float lat2, float lon2) {
    const float EARTH_RADIUS = 6371000.0;  // meters
    const float PI = 3.14159265;
    
    float dLat = (lat2 - lat1) * PI / 180.0;
    float dLon = (lon2 - lon1) * PI / 180.0;
    
    float a = sin(dLat / 2) * sin(dLat / 2) +
              cos(lat1 * PI / 180.0) * cos(lat2 * PI / 180.0) *
              sin(dLon / 2) * sin(dLon / 2);
    
    float c = 2 * atan2(sqrt(a), sqrt(1 - a));
    
    return EARTH_RADIUS * c;
}

void setHomePosition(float lat, float lon) {
    geofence.homeLat = lat;
    geofence.homeLon = lon;
    geofence.homeSet = true;
    geofence.violated = false;
    Serial.print("GEOFENCE: Home set to ");
    Serial.print(lat, 6);
    Serial.print(", ");
    Serial.println(lon, 6);
}

void updateGPS(float lat, float lon, uint32_t fixAge) {
    // GPS GHOSTING FIX: Ignore invalid coordinates
    if (fixAge > GPS_VALID_AGE_MS) {
        return;  // Ignore stale fixes
    }
    
    // Ignore zero coordinates (GPS loss = 0.00,0.00)
    if (lat == 0.0 && lon == 0.0) {
        return;  // Invalid GPS - likely no fix
    }
    
    geofence.currentLat = lat;
    geofence.currentLon = lon;
    geofence.lastValidFix = millis();
    
    if (!geofence.homeSet) {
        // First valid fix - set as home
        setHomePosition(lat, lon);
        return;
    }
    
    // Check distance from home
    float distance = calculateDistance(
        geofence.homeLat, geofence.homeLon,
        lat, lon
    );
    
    if (distance > GEOFENCE_RADIUS_M && !geofence.violated) {
        geofence.violated = true;
        Serial.print("GEOFENCE: VIOLATION! Distance: ");
        Serial.println(distance);
    } else if (distance <= GEOFENCE_RADIUS_M * 0.8) {
        // Clear violation when back within 80% of fence (hysteresis)
        geofence.violated = false;
    }
}

bool isGeofenceViolated() {
    return geofence.violated;
}

bool isGPSValid() {
    return (millis() - geofence.lastValidFix) < GPS_VALID_AGE_MS;
}

// =============================================================================
// CHARGING SAFETY MODULE
// =============================================================================
// When docked:
// - Immediately stop all motors
// - Enter reduced-power sensor mode
// - Keep critical monitoring active
// - Log charge start timestamp
// - Attempt charge completion detection
// Non-blocking state machine

#define CHARGE_COMPLETE_VOLTAGE 8.4   // 4.2V per cell for 2S
#define CHARGE_COMPLETE_TIME    600000  // 10 minutes max charge

static bool chargeStarted = false;
static uint32_t chargeStartTime = 0;
static bool chargeComplete = false;
static bool chargeBeepDone = false;  // Reset on undock

void onDockDetected() {
    chargeStarted = true;
    chargeStartTime = millis();
    chargeComplete = false;
    
    Serial.println("CHARGING: Dock detected - starting charge");
}

void onUndocked() {
    chargeStarted = false;
    chargeStartTime = 0;
    chargeComplete = false;
    chargeBeepDone = false;  // Reset for next charge cycle
    
    Serial.println("CHARGING: Undocked - resetting charge state");
}

bool isChargingComplete(float voltage) {
    if (!chargeStarted || chargeComplete) {
        return chargeComplete;
    }
    
    // Check voltage threshold
    if (voltage >= CHARGE_COMPLETE_VOLTAGE) {
        chargeComplete = true;
        Serial.println("CHARGING: Complete - voltage threshold reached");
        return true;
    }
    
    // Check timeout
    if ((millis() - chargeStartTime) > CHARGE_COMPLETE_TIME) {
        chargeComplete = true;
        Serial.println("CHARGING: Complete - timeout");
        return true;
    }
    
    return false;
}

bool hasChargingStarted() {
    return chargeStarted;
}

// =============================================================================
// GSM ALERT ROUTINES - HARDENED SIM800L
// =============================================================================
// Non-blocking with retry, network registration, graceful failure
// Status: Ready, Searching, NoSim, Failed

#define GSM_INIT_TIMEOUT_MS  30000   // 30 seconds to initialize
#define SMS_RETRY_MAX        3        // Max SMS retry attempts
#define SMS_RETRY_DELAY_MS  5000     // 5 seconds between retries

enum GSMStatus {
    GSM_OFFLINE = 0,
    GSM_INIT,
    GSM_SEARCHING,
    GSM_READY,
    GSM_FAILED
};

struct GSMState {
    GSMStatus status;
    uint32_t initStartTime;
    uint8_t retryCount;
    String phoneNumber;
    bool smsInProgress;
};

static GSMState gsm = {
    GSM_OFFLINE, 0, 0, "+1234567890", false
};

/**
 * Non-blocking GSM initialization
 * Call repeatedly from task
 * Returns true when ready to send SMS
 */
bool updateGSM() {
    uint32_t now = millis();
    
    switch (gsm.status) {
        case GSM_OFFLINE:
            // Start initialization
            gsm.status = GSM_INIT;
            gsm.initStartTime = now;
            gsm.retryCount = 0;
            Serial.println("GSM: Starting init...");
            // FIX C4: Serial2 is used by GPS (NEO-6M on pins 8,19).
            // SIM800L (pins 12,13) MUST use Serial1 to avoid corrupting GPS stream.
            Serial1.begin(9600, SERIAL_8N1, SIM800_RX, SIM800_TX);
            break;
            
        case GSM_INIT:
            // Wait for AT response
            if (now - gsm.initStartTime > 2000) {
                Serial1.println("AT");
                gsm.initStartTime = now;
            }
            if (Serial1.available()) {
                String response = "";
                while (Serial1.available()) {
                    response += (char)Serial1.read();
                }
                if (response.indexOf("OK") >= 0) {
                    gsm.status = GSM_SEARCHING;
                    gsm.initStartTime = now;
                    Serial.println("GSM: AT OK - searching network...");
                }
            }
            // Timeout after 30 seconds
            if (now - gsm.initStartTime > GSM_INIT_TIMEOUT_MS) {
                gsm.status = GSM_FAILED;
                Serial.println("GSM: Init failed - timeout");
            }
            break;
            
        case GSM_SEARCHING:
            // Wait for network registration
            if (now - gsm.initStartTime > 1000) {
                Serial1.println("AT+CREG?");
                gsm.initStartTime = now;
            }
            if (Serial1.available()) {
                String response = "";
                while (Serial1.available()) {
                    response += (char)Serial1.read();
                }
                // CREG: 1 = Registered, home, 5 = Registered, roaming
                if (response.indexOf(",1") >= 0 || response.indexOf(",5") >= 0) {
                    gsm.status = GSM_READY;
                    Serial.println("GSM: Network registered - READY");
                }
            }
            // Timeout after 60 seconds
            if (now - gsm.initStartTime > 60000) {
                gsm.status = GSM_FAILED;
                Serial.println("GSM: Network registration failed");
            }
            break;
            
        case GSM_READY:
            // Ready for SMS
            break;
            
        case GSM_FAILED:
            // Attempt recovery every 60 seconds
            if (now - gsm.initStartTime > 60000) {
                gsm.status = GSM_OFFLINE;
                gsm.initStartTime = now;
            }
            break;
    }
    
    return (gsm.status == GSM_READY);
}

/**
 * Send SMS with retry logic (non-blocking)
 * Returns: true if sent, false if failed/retrying
 */
bool sendSMS_Hardened(const char* message) {
    static uint32_t retryStartTime = 0;
    static const char* pendingMessage = NULL;
    
    if (gsm.status != GSM_READY) {
        return false;
    }
    
    // If we have a pending message being sent
    if (pendingMessage != NULL) {
        if (Serial1.available()) {
            String response = "";
            while (Serial1.available()) {
                response += (char)Serial1.read();
            }
            
            if (response.indexOf(">") >= 0) {
                // Ready for message body
                Serial1.print(pendingMessage);
                Serial1.write(26);  // Ctrl+Z
                retryStartTime = millis();
            }
            else if (response.indexOf("OK") >= 0) {
                // Message sent successfully
                Serial.println("GSM: SMS sent successfully");
                pendingMessage = NULL;
                gsm.retryCount = 0;
                return true;
            }
            else if (response.indexOf("ERROR") >= 0 || (millis() - retryStartTime > 10000)) {
                // Failed - retry
                gsm.retryCount++;
                if (gsm.retryCount >= SMS_RETRY_MAX) {
                    Serial.println("GSM: SMS failed after max retries");
                    pendingMessage = NULL;
                    gsm.retryCount = 0;
                    return false;
                }
                Serial.print("GSM: SMS retry ");
                Serial.println(gsm.retryCount);
                retryStartTime = millis();
                // Will retry in next call
            }
        }
        return false;  // Still in progress
    }
    
    // Start new SMS
    if (gsm.retryCount < SMS_RETRY_MAX) {
        pendingMessage = message;
        Serial1.print("AT+CMGS=\"");
        Serial1.print(gsm.phoneNumber);
        Serial1.println("\"");
        retryStartTime = millis();
    }
    
    return false;
}

bool isGSReady() {
    return (gsm.status == GSM_READY);
}

/**
 * SIM800 Flood Protection: Cooldown timer
 * Prevents SMS spam if condition persists
 */
#define SMS_COOLDOWN_MS 60000  // 60 seconds between SMS
static uint32_t lastSMSTime = 0;

bool safeSendSMS(const char* message) {
    // SMS FLOOD PROTECTION: Rate limit to once per 60 seconds
    uint32_t now = millis();
    if (now - lastSMSTime < SMS_COOLDOWN_MS) {
        return false;  // Still in cooldown
    }
    
    // Save current motor state
    uint8_t savedSpeed = currentSpeed;
    int8_t savedTurn = currentTurn;
    
    // STOP MOTORS before SMS - prevent brownout
    currentSpeed = 0;
    currentTurn = 0;
    drive(0, 0);
    
    // Wait for rail to stabilize (100ms)
    delay(100);
    
    // Send SMS
    bool result = sendSMS_Hardened(message);
    
    // Update cooldown if SMS was actually sent
    if (result) {
        lastSMSTime = now;
    }
    
    // Restore motor state (will ramp back smoothly via driveRamped)
    currentSpeed = savedSpeed;
    currentTurn = savedTurn;
    
    return result;
}

void sendGeofenceAlert() {
    if (alertSent) return;
    
    char msg[100];
    snprintf(msg, sizeof(msg), 
        "STASIS: Geofence breach! Lat: %.5f Lon: %.5f",
        (double)latitude, (double)longitude);
    
    if (safeSendSMS(msg)) {
        alertSent = true;
    }
}

void sendHazardAlert(AlertType type) {
    if (alertSent) return;
    
    const char* msg = "STASIS: Hazard detected";
    
    if (type == ALERT_FIRE) {
        msg = "STASIS: FIRE DETECTED! Immediate attention!";
    } else if (type == ALERT_EARTHQUAKE) {
        msg = "STASIS: Seismic activity detected";
    }
    
    if (safeSendSMS(msg)) {
        alertSent = true;
    }
}
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
void loop() {
    // Main loop - most work done in tasks
    // Periodic safety check
    if (estopTriggered) {
        estop();
    }
    
    // Watchdog reset
    // esp_task_wdt_reset();
    
    delay(10);
}

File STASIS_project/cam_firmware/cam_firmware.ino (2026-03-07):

/**
 * ============================================================================
 * STASIS - ESP32-CAM VISION MODULE FIRMWARE
 * ============================================================================
 * 
 * This module handles:
 * - Image capture and processing
 * - Fire detection (color + brightness analysis)
 * - Motion detection (frame differencing)
 * - Human detection (simple pattern analysis)
 * - Streaming frames to ESP32-S3 on command
 * 
 * Communication Protocol with ESP32-S3:
 * - 0x01: CAPTURE - Take single image and return detection result
 * - 0x02: STREAM_ON - Start continuous frame streaming
 * - 0x03: STREAM_OFF - Stop streaming
 * - 0x04: DETECT - Run detection and return result
 * 
 * Response Format:
 * - DetectionResult struct with fire/motion/human flags
 * - Or simple text: "HAZARD:FIRE", "HAZARD:MOTION", "HAZARD:HUMAN", "CLEAR"
 * 
 * ============================================================================
 */

#include <Arduino.h>
#include <esp_camera.h>

// ============================================================================
// CAMERA PIN DEFINITIONS (AI Thinker ESP32-CAM)
// ============================================================================
#define PWDN_GPIO_NUM  32
#define RESET_GPIO_NUM -1
#define XCLK_GPIO_NUM  0
#define SIOD_GPIO_NUM  26
#define SIOC_GPIO_NUM  27
#define Y9_GPIO_NUM    35
#define Y8_GPIO_NUM    34
#define Y7_GPIO_NUM    39
#define Y6_GPIO_NUM    36
#define Y5_GPIO_NUM    21
#define Y4_GPIO_NUM    19
#define Y3_GPIO_NUM    18
#define Y2_GPIO_NUM    5
#define VSYNC_GPIO_NUM 25
#define HREF_GPIO_NUM  23
#define PCLK_GPIO_NUM  22

// Status LED (built-in)
#define LED_PIN 4

// ============================================================================
// COMMAND PROTOCOL
// ============================================================================
typedef enum {
  CMD_CAPTURE    = 0x01,
  CMD_STREAM_ON  = 0x02,
  CMD_STREAM_OFF = 0x03,
  CMD_DETECT     = 0x04
} CamCommand;

// ============================================================================
// DETECTION RESULT STRUCTURE
// ============================================================================
typedef struct __attribute__((packed)) {
  bool  fire;
  bool  motion;
  bool  human;
  float confidence;
  char  description[24];
} DetectionResult;

// ============================================================================
// DETECTION THRESHOLDS (Configurable)
// ============================================================================
#define FIRE_PIXEL_THRESHOLD    15    // Minimum fire pixels to trigger
#define MOTION_PIXEL_THRESHOLD  30    // Minimum motion pixels to trigger
#define MOTION_SENSITIVITY      4000  // Pixel difference threshold
#define FIRE_R_MIN              25    // Red channel minimum for fire
#define FIRE_G_MIN              10    // Green channel minimum for fire
#define FIRE_B_MAX              8     // Blue channel maximum for fire

// ============================================================================
// GLOBAL VARIABLES
// ============================================================================
static uint16_t prevFrameBuf[320 * 240 / 50];  // Downsampled previous frame
static bool     streamingEnabled = false;
static bool     cameraReady = false;

// Detection statistics
static uint16_t firePixels = 0;
static uint16_t motionPixels = 0;
static uint16_t humanPixels = 0;

// ============================================================================
// CAMERA INITIALIZATION
// ============================================================================
bool initCamera() {
  camera_config_t config;
  
  config.ledc_channel   = LEDC_CHANNEL_0;
  config.ledc_timer     = LEDC_TIMER_0;
  config.pin_d0         = Y2_GPIO_NUM;
  config.pin_d1         = Y3_GPIO_NUM;
  config.pin_d2         = Y4_GPIO_NUM;
  config.pin_d3         = Y5_GPIO_NUM;
  config.pin_d4         = Y6_GPIO_NUM;
  config.pin_d5         = Y7_GPIO_NUM;
  config.pin_d6         = Y8_GPIO_NUM;
  config.pin_d7         = Y9_GPIO_NUM;
  config.pin_xclk       = XCLK_GPIO_NUM;
  config.pin_pclk       = PCLK_GPIO_NUM;
  config.pin_vsync      = VSYNC_GPIO_NUM;
  config.pin_href       = HREF_GPIO_NUM;
  config.pin_sscb_sda   = SIOD_GPIO_NUM;
  config.pin_sscb_scl   = SIOC_GPIO_NUM;
  config.pin_pwdn       = PWDN_GPIO_NUM;
  config.pin_reset      = RESET_GPIO_NUM;
  config.xclk_freq_hz   = 20000000;
  config.pixel_format   = PIXFORMAT_RGB565;
  config.frame_size     = FRAMESIZE_QVGA;  // 320x240 for faster processing
  config.jpeg_quality   = 12;
  config.fb_count       = 2;  // Double buffer for streaming

  // Try to initialize camera with retry
  for (int attempt = 0; attempt < 3; attempt++) {
    if (esp_camera_init(&config) == ESP_OK) {
      cameraReady = true;
      return true;
    }
    delay(500);
  }
  
  return false;
}

// ============================================================================
// DETECTION ALGORITHMS
// ============================================================================
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

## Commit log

2026-02-19 Fix duplicate code and expand main files to 1000+ lines
    [base_bridge.ino, cam_firmware.ino, rover_main.ino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]
2026-02-21 feat: Configure ESP32-C3 as GPIO extender for RPi0W
2026-02-21 fix: Remove duplicate code in base_bridge.ino (restored from initial commit)
    [base_bridge.ino, cam_firmware.ino, station_monitor.py]
2026-02-21 Update ESP32-C3 docs: Add GPIO extender role, LCD display support, and AprilTag docking guide
2026-02-21 Fix ESP32-S3 compilation errors for ESP-IDF 3.3.7: Update ESP-NOW callbacks and WDT API
    [rover_main.ino]
2026-02-21 Fix ESP-NOW send callback type: use wifi_tx_info_t instead of wifi_pkt_tx_info_t
    [rover_main.ino]
2026-02-22 Update documentation with latest firmware features and add 3D printed parts guide
    [Long leg resized-Body.stl, base resized-Body.stl, base-Body.stl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]
2026-02-22 refactor: rename ESP32-S3 firmware to .ino and restructure
2026-02-22 Reorganize project structure to match README layout
    [Long leg resized-Body.stl, base resized-Body.stl, base-Body.stl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]
2026-02-22 Fix duplicate code in firmware files and UART.read error
    [cam_firmware.ino, rover_main.ino]
2026-02-22 Fix duplicate function definitions in .ino files
    [cam_firmware.ino, rover_main.ino]
2026-02-22 Fix rover_main.ino: Update LEDC API for ESP32 Arduino Core 3.x
    [rover_main.ino]
2026-02-22 Fix RoverProject/rover_s3_firmware: Update LEDC API for ESP32 Arduino Core 3.x
    [rover_main.ino]
2026-02-22 Fix base_bridge: Update ESP-NOW callbacks for ESP32 Arduino Core 3.x
    [base_bridge.ino]
2026-02-22 Remove duplicate RoverProject folder - keep only root level files
    [Long leg resized-Body.stl, base resized-Body.stl, base-Body.stl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]
2026-02-24 Rebrand to Stasis, fix bugs, add Sentinel web app
    [apriltag_docking.py, base_bridge.ino, rover_main.ino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]
2026-02-27 Fix login modal and permissions - guests can now control rover
    - Fixed guest login modal not hiding properly
    - Guests now have full control permissions (rover, fencing, chat)
    - Added WebSocket support to station_monitor.py for real-time chat
    - Added human detection support in ESP32-CAM firmware
    - Improved chat functionality with proper event listeners
    [station_monitor.py]
2026-02-28 Fix buttons - add pointer-events auto everywhere
2026-02-28 Nice UI with working buttons - dark blue theme
2026-02-28 Add camera hazard handling and complete rover commands
    - Add handle_non_json_message() for parsing HAZARD:FIRE, HAZARD:HUMAN messages
    - Add all rover commands (PATROL, HOME, DOCKING, START_RESEARCH, etc.)
    - Fix login modal in web app
    - Update README with new features and simplify dashboard setup
    [station_monitor.py]
2026-02-28 Update documentation to match current code
    - PROTOCOL.md: Add camera hazard messages (HAZARD:FIRE, etc.) and all rover commands
    - RPI0_INSTRUCTIONS.md: Add flask-socketio dependency, fix duplicate content
    - README.md: Add API_KEY environment variable and authentication info
2026-02-28 Add command handling and camera message forwarding to ESP firmware
    rover_main.ino:
    - Add STATE_IDLE for default idle state
    - Add command parsing for STOP, FORWARD, BACKWARD, LEFT, RIGHT
    - Add commands: PATROL, STOP_PATROL, HOME, RESEARCH, DOCKING, RESET
    - Add cameraTask to forward HAZARD messages from camera to Pi
    - Parse camera hazard messages (HAZARD:FIRE, HAZARD:MOTION, HAZARD:HUMAN)
    base_bridge.ino:
    - Add processRoverMessages() to forward non-JSON messages to Pi
    - HAZARD:*, CAM:*, ERROR:* messages now properly forwarded
    [base_bridge.ino, rover_main.ino]
2026-02-28 Update wiring diagrams to match current firmware
    - Add system overview with communication flow
    - Update ESP32-S3 pins: Camera now uses UART0 (GPIO 1/3), Pi uses UART1 (GPIO 43/44)
    - Add complete data flow diagram
    - Update pin reference tables with correct GPIO assignments
    - Document HAZARD message path: Camera → Rover → Bridge → Pi
2026-02-28 Add SSH setup guide for Pi Zero wired connection
    - Method 1: USB Ethernet (recommended)
    - Method 2: Serial console with TTL adapter
    - Method 3: Ethernet hub
    - Troubleshooting tips
    - SSH key setup
    - First-time Pi setup instructions
2026-03-01 Complete STASIS rover firmware with all required features
    Implemented Features:
    - State Machine: SAFE_IDLE, PATROL, ALERT, RETURN_TO_BASE, DOCKING, DOCKED_CHARGING
    - Dock Detection: Battery voltage rise with baseline-relative detection and debouncing
    - GPS Geofence: Haversine distance calculation, 50m radius, non-blocking
    - Charging Safety: Motor stop, reduced power mode, charge complete detection
    - GSM Alerts: SIM800L SMS for geofence violation and hazard detection
    - Motor Control: L9110S 4WD differential drive, non-blocking
    - Non-blocking: All timing using millis(), no delay() in control loops
    - AprilTag Docking: UART protocol with Pi Zero for precision guidance
    Fixes:
    - Removed duplicate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
    [rover_main.ino]
2026-03-01 HARDENING PASS - Production reliability improvements
    Repository:
    - Removed duplicate rover_s3_firmware directory
    - Canonical firmware: rover_main/rover_main.ino
    State Machine:
    - Added minimum state time guard (500ms) to prevent flapping
    - Safe motor shutdown on all critical transitions
    Dock Detection:
    - Baseline-relative voltage rise detection (0.4V threshold)
    - 10-sample baseline averaging
    - 2s dock confirm, 1.5s undock debounce
    - Hysteresis to prevent chatter
    GSM Hardening:
    - Non-blocking initialization with network registration
    - Retry logic (3 attempts, 5s backoff)
    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
    [rover_main.ino]
2026-03-01 Final hardening - motor ramping and startup fix
    Motor Control:
    - Added speed ramping (SPEED_RAMP_RATE = 5) for smooth acceleration
    - Prevents sudden motor movements
    - Resets ramp speeds on estop()
    - Fixed guard to allow first state transition without delay
    - Prevents startup freeze
    All hardening complete for competition.
    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
    [rover_main.ino]
2026-03-03 Repository unification and final hardening
    Phase 1 - Repository:
    - Confirmed canonical firmware: rover_main/rover_main.ino
    - All subsystems properly organized
    Phase 2 - Protocol:
    - docs/PROTOCOL.md contains full specification
    Phase 7 - Base Station:
    - Added exponential backoff for serial reconnect
    - Added stale telemetry detection
    - Added defensive JSON parsing
    - Better error handling
    Phase 9 - README:
    - Replaced with exact specified content
    [station_monitor.py]
2026-03-03 Surgical patches - 4 demo-day bug fixes
    1. Ultrasonic: Increased timeout from 25ms to 30ms (30000us)
    - Prevents 1-second freeze on sensor echo miss
    2. SIM800: Added safeSendSMS() wrapper
    - Stops motors before SMS to prevent brownout
    - 100ms rail stabilization delay
    - Restores motor state after send
    3. GPS Ghosting: Added validity check for lat/lon
    - Ignores 0.0,0.0 coordinates
    - Prevents false geofence breach on GPS loss
    4. Docking Debounce: Added 20-frame counter
    - DOCK_DEBOUNCE_FRAMES = 20
    - Requires 20 consecutive voltage rise frames to confirm dock
    - Prevents single spike false positives
    [rover_main.ino]
2026-03-03 GPS Staleness Fix: Add SAFE_HALT when GPS older than 5s
    If rover enters GPS dead zone (indoor hall), it now halts safely instead of driving blindly.
    [rover_main.ino]
2026-03-03 SMS Flood Fix: Add 60-second cooldown to prevent SIM800 spam
    If hazard condition persists, only send 1 SMS per 60 seconds to protect SIM800 and battery.
    [rover_main.ino]
2026-03-03 Update docs: ESP32-S3 guide rewritten, add QUICK_REFERENCE.md
2026-03-03 Add DS18B20 and LDR sensor functions
    - Add LDR_PIN definition (GPIO 0)
    - Add EnvSensor struct for both sensors
    - Add initTemperatureSensor() and initLDR()
    - Add readTemperature() - DS18B20
    - Add readLDR() with moving average
    - Add getLightPercent()
    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
2026-03-07 fix: all critical patches + AprilTag docking implemented also :3
    [cam_firmware.ino, rover_main.ino, station_monitor.py]
